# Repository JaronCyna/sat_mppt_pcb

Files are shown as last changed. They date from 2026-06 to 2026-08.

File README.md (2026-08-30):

# CubeSat 4-Channel Distributed MPPT & Electrical Power System (EPS)

A flight-ready 4-channel distributed Maximum Power Point Tracking (MPPT) battery charging and power distribution board designed in KiCad for CubeSat nanosatellite missions. Engineered for the Queen's Space Engineering Team (QSET) satellite branch.

---

## Key Features

* **4x Distributed Synchronous MPPT Buck Chargers (LTC4162)**:
  * 4 independent MPPT tracking channels (1 per CubeSat body face), eliminating partial shading and thermal mismatch losses across orbit.
  * Autonomous Constant-Current / Constant-Voltage (CC/CV) power-path management charging a 2S Li-ion battery bus (~8.4V nominal).
  * Phase-synchronized 1.5 MHz switching frequency via MCU clock distribution buffer to prevent harmonic beat frequencies and reduce EMI.
* **Microcontroller & Rad-Tolerant Storage Core**:
  * **STM32L496 ARM Cortex-M4**: Ultra-low-power MCU handling housekeeping telemetry, fault recovery, and bus communications.
  * **4 MB Radiation-Hardened MRAM**: Immune to Single-Event Upsets (SEU) and Total Ionizing Dose (TID), preserving black-box flight telemetry across power resets.
  * **4-Pin High-Vibration Crystal Oscillator**: Superior mechanical stability against rocket launch vibrational loads compared to traditional 2-pin crystals.
  * **Deterministic Hardware Watchdog (TPS3823A)**: Hardware supervisor with active-low reset and Schottky diode isolation protecting against SEU lockups in LEO.
* **Satellite Bus Communications & Auxiliary Power Path**:
  * **Dual Redundant CAN Bus Transceivers**: Conforms to European CubeSat standard bus communication architecture.
  * **I2C Bus Multiplexer (TI TCA9548A)**: 8-channel I2C switch addressing 4 identical LTC4162 chargers at fixed I2C addresses.
  * **Dual Synchronous Buck Converter (LTC3633)**: Monolithic dual synchronous buck generating regulated +3.3V and +5.0V system rails (<15 mV ripple).
  * **Autonomous Power-Path & Cold-Start (LTC4412)**: Ideal diode controller providing seamless fallback between battery and direct solar harvest for dead-battery bootstrapping.
* **Power Telemetry & Comprehensive eFuse Protection**:
  * **INA3221 Triple-Channel Current/Voltage Monitor**: Digital I2C telemetry reporting bus voltages, currents, and power consumption.
  * **TPS25947 Precision eFuses**: Dedicated protection on output rails with programmable current limits (1.33 A clamp on +3.3V), slew rate inrush control (5 V/ms), transient blanking (0.44 ms), hardware UVLO/OVLO windowing (3.02 V – 3.63 V), and remote MCU/OBC shutdown.
* **Form Factor & Mechanical Integrity**:
  * Standard PC/104 CubeSat stackable form factor.
  * Dedicated battery interface with 4-wire Kelvin sensing and NTC thermistor inputs.
  * 6-Layer stackup with solid ground reference planes, top-side RF/switching hot loops, and vibration-resistant soft-termination MLCC capacitors.

---

## System Architecture & PCB Renders

### Full Board 3D Model
Full Board 3D Model

### Top & Bottom Layout Renders
| Top Layer (Switching & Hot Loops) | Bottom Layer (Routing & Ground Shield) |
| :---: | :---: |
| Top Board | Bottom Board |

### Top-Level Hierarchical Schematic
Top-Level Schematic

---

## Technical Specifications

| Parameter | Specification / Value | Engineering Notes |
| :--- | :--- | :--- |
| **Solar Input Channels** | 4 independent MPPT channels | 1 channel per satellite face (up to ~18V $V_{\text{oc}}$ per string) |
| **Battery Bus Configuration** | 2S Li-ion (6.0V – 8.4V) | Direct autonomous CC/CV charging |
| **MPPT Switching Frequency** | 1.5 MHz (Synchronized) | Phase-locked via MCU PWM buffer to eliminate beat frequencies |
| **+3.3V Regulated Bus** | 3.3V @ 3A max (<15 mV ripple) | Generated by LTC3633 monolithic buck; eFuse clamped at 1.33A |
| **+5.0V Regulated Bus** | 5.0V @ 3A max (<15 mV ripple) | Generated by LTC3633 monolithic buck |
| **Telemetry Storage** | 4 MB SPI MRAM | Immune to SEU and TID radiation effects in LEO |
| **Bus Interfaces** | Dual CAN Bus + I2C | Redundant CubeSat standard bus communication |
| **PCB Stackup** | 6-Layer FR4 (1.6mm) | Top: Switching, L2: GND, L3: Mix, L4: Mix, L5: GND, L6: Digital |
| **Mechanical Standard** | PC/104 CubeSat Standard | Custom battery interface with Kelvin sense + NTC |

---

## Power Telemetry & eFuse Configuration

Each regulated rail is protected by a TI TPS25947 eFuse and monitored by a TI INA3221 current/voltage telemetry IC:

* **Current Limit Threshold ($I_{\text{LIM}}$)**:
  $$I_{\text{LIM}} = \frac{13.33}{R_{\text{ILIM}}\ [\text{k}\Omega]} = \frac{13.33}{10\text{ k}\Omega} = 1.33\text{ A}$$
* **Output Slew Rate & Inrush Control ($\frac{dV}{dt}$)**:
  $$\frac{dV}{dt} = \frac{500}{C_{dV/dt}\ [\text{pF}]} = \frac{500}{100\text{ pF}} = 5\text{ V/ms}$$
* **Overcurrent Fault Blanking Timer ($t_{\text{ITIMER}}$)**:
  $$t_{\text{ITIMER}} = C_{\text{ITIMER}}\ [\text{nF}] \times 0.2 = 2.2\text{ nF} \times 0.2 = 0.44\text{ ms}$$
* **Voltage Window (UVLO / OVLO)**:
  $$\text{Operational Window: } 3.02\text{ V} \le V_{\text{IN}} \le 3.63\text{ V}$$

---

## Hierarchical Schematic Structure

The hardware schematic is split into modular hierarchical sheets:

| Schematic Sheet | Description | Primary Components |
| :--- | :--- | :--- |
| `EPS_mppt_board.kicad_sch` | Root top-level hierarchical sheet | Interconnects and top-level bus routing |
| `MPPT_IC.kicad_sch` | Quad MPPT top-level sheet | 4x instances of `MPPT_indv.kicad_sch` |
| `MPPT_indv.kicad_sch` | Single-channel MPPT buck charger | LTC4162, power inductors, input/output caps |
| `3.3V.kicad_sch` | Dual synchronous buck converter | LTC3633 (generates +3.3V and +5.0V rails) |
| `MPPT_3.3V_logic.kicad_sch` | Power-path and bootstrapping | LTC4412 Ideal Diode Controller |
| `Sensing.kicad_sch` | Power telemetry and fault protection | INA3221 monitor, TPS25947 eFuses |
| `STM32L4.kicad_sch` | Microcontroller, MRAM, and clocking | STM32L496, 4MB MRAM, 4-pin OSC, 1:6 PWM buffer |
| `I2C.kicad_sch` | I2C bus multiplexer | TCA9548A 8-channel I2C switch |
| `External Watchdog IC.kicad_sch` | Deterministic hardware supervisor | TPS3823A watchdog IC + Schottky pull-up |
| `PC104.kicad_sch` | Satellite bus interface & connectors | PC/104 bus header, battery Kelvin sense, solar inputs |

---

## Repository Structure

```
Sat_MPPT_PCB/
├── .gitignore                      # Standard KiCad ignore rules
├── README.md                       # Board documentation and specifications
│
├── docs/                           # Documentation & exports
│   ├── bom/
│   │   └── EPS_mppt_board.csv      # Complete Bill of Materials
│   ├── pdf/
│   │   └── EPS_mppt_board.pdf      # Complete schematic PDF
│   └── svg/                        # Exported vector schematics per sheet
│       ├── EPS_mppt_board.svg
│       ├── EPS_mppt_board-3.3V Logic.svg
│       ├── EPS_mppt_board-MPPT IC.svg
│       └── ...
│
├── scripts/                        # Simulation & analysis tools
│   └── mppt_efficiency_sim.py      # 4-MPPT vs 1-MPPT orbital comparison simulation
│
├── archive/                        # Early design prototypes and iterations
│   └── prototypes/
│
├── 3D_Models/                      # 3D STEP/STP component models
│
├── sym-lib-table                   # KiCad Symbol Library Table
├── *.kicad_sym                     # Custom project symbol libraries
│
├── EPS_mppt_board.kicad_pro        # KiCad Project File
├── EPS_mppt_board.kicad_sch        # Root Schematic
├── EPS_mppt_board.kicad_pcb        # PCB Layout File
└── *.kicad_sch                     # Hierarchical Sub-schematics
```

---

## Simulation & Verification

* **Switching & Transient Simulations**:
  LTspice models verified buck converter stability, hot-loop parasitic response, and transient load step response (0.1A to 3.0A step with <15 mV voltage deviation).

* **SPICE**:
  All IC's with available SPICE models were simullated in PSPICE or LTSPICE.

---

## Project Background

* **Detailed Technical Writeup**: Read the full post on [Creating an MPPT System for Max Charge Efficiency on Satellite](https://jaroncyna.github.io/posts/MPPT-Satellite-Charger/)

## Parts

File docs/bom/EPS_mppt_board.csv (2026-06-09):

Reference | Qty | DNP | Exclude from BOM | Exclude from Board | Footprint | Datasheet | MANUFACTURER_PART_NUMBER | MANUFACTURER | Description
C1,C4,C5,C8,C11,C66,C67,C73,C74,C76 | 10 |  |  |  | Capacitor_SMD:C_0603_1608Metric | https://mm.digikey.com/Volume0/opasdata/d220001/medias/docus/2113/CL32B226KAJNFNE_Spec.pdf | 06035C104K4T2A | DigiKey | Unpolarized capacitor
C2,C58,C68,C69,C70 | 5 |  |  |  | Capacitor_SMD:C_0603_1608Metric | https://mm.digikey.com/Volume0/opasdata/d220001/medias/docus/2113/CL32B226KAJNFNE_Spec.pdf | CL10B105KQ8NNNC | DigiKey | Unpolarized capacitor
C3,C6,C7,C88,C89 | 5 |  |  |  | zLibrary:CAP_C2220C_2S_KEM-M |  | C2220C226MMR2L7289 | DigiKey | Unpolarized capacitor
C9,C77,C79,C81 | 4 |  |  |  | Capacitor_SMD:C_0603_1608Metric |  | GCM1885C1H222FA16D | DigiKey | Unpolarized capacitor
C10,C78,C80,C82 | 4 |  |  |  | Capacitor_SMD:C_0603_1608Metric |  | 885342206001 | DigiKey | Unpolarized capacitor
C12 | 1 |  |  |  | Capacitor_SMD:C_0603_1608Metric |  | C0603W102KDRACAUTO | DigiKey | Unpolarized capacitor
C13,C52,C53,C54,C55,C56,C57,C59,C62,C64,C65 | 11 |  |  |  | Capacitor_SMD:C_0603_1608Metric | kicad-embed://KEM_C1013_X7R_FT-CAP_SMD.pdf | C0603X104K5RACTU | DigiKey | Unpolarized capacitor,kicad-embed://KEM_C1013_X7R_FT-CAP_SMD.pdf
C14,C23,C32,C41 | 4 |  |  |  | Capacitor_SMD:C_0603_1608Metric | kicad-embed://CL10B105KQ8NNNC_Spec.pdf | CL10B105KQ8NNNC | DigiKey | Unpolarized capacitor
C15,C24,C33,C42 | 4 |  |  |  | Capacitor_SMD:C_0603_1608Metric |  | CL10B475KQ8NQNC | DigiKey | Unpolarized capacitor
C16,C22,C25,C31,C34,C40,C43,C49,C63 | 9 |  |  |  | zLibrary:CAP_C1210C_X7R_2S_FW_KEM-M |  | C1210C106M5R2C7186 | DigiKey | Unpolarized capacitor
C17,C18,C26,C27,C35,C36,C44,C45,C83,C84,C85,C87 | 12 |  |  |  | Capacitor_SMD:C_0603_1608Metric | ~ | 06035C104K4T2A | DigiKey | Unpolarized capacitor
C19,C28,C37,C46 | 4 |  |  |  | Capacitor_SMD:C_0603_1608Metric | ~ | CGA3E2X7R1H223K080AA | DigiKey | Unpolarized capacitor
C20,C29,C38,C47 | 4 |  |  |  | Capacitor_Tantalum_SMD:CP_EIA-7361-38_AVX-V | kicad-embed://t52.pdf | T52M9107M035C0055 | DigiKey | Unpolarized capacitor
C21,C30,C39,C48 | 4 |  |  |  | zLibrary:CAP_C2220C_2S_KEM-M |  | C2220C226MMR2L7289 | DigiKey | https://mm.digikey.com/Volume0/opasdata/d220001/medias/docus/2113/CL32B226KAJNFNE_Spec.pdf
C50 | 1 |  |  |  | Capacitor_Tantalum_SMD:CP_EIA-7361-38_AVX-V | kicad-embed://t52.pdf | T52M9107M035C0055 | DigiKey | Polarized capacitor, US symbol
C51 | 1 |  |  |  | Capacitor_SMD:C_0603_1608Metric |  | CL10B475KQ8NQNC | DigiKey | Unpolarized capacitor
C60,C61 | 2 |  |  |  | Capacitor_SMD:C_0603_1608Metric |  | 06035C100K4T4A | DigiKey | Unpolarized capacitor
C71,C72,C75 | 3 |  |  |  | zLibrary:CAP_C1210C_X7R_2S_FW_KEM-M |  | C1210C106M5R2C7186 | DigiKey | Unpolarized capacitor
C86 | 1 |  |  |  | Capacitor_SMD:C_0603_1608Metric |  | GRM188Z71E225KE43D | DigiKey | Unpolarized capacitor
D1 | 1 |  |  | Excluded from board | Diode_SMD:D_SOD-323F | ~ | RBE01VYM6AFHTR | Digikey | Schottky diode
D6 | 1 |  |  |  | LED_SMD:LED_0603_1608Metric |  | 150060RS55040 | DigiKey | Light emitting diode
D7 | 1 |  |  |  | LED_SMD:LED_0603_1608Metric |  | 150060VS55040 | DigiKey | Light emitting diode
D8 | 1 |  |  |  | LED_SMD:LED_0603_1608Metric |  | 150060BS55040 | DigiKey | Light emitting diode
D9,D10,D11,D12 | 4 |  |  |  | Diode_SMD:D_SMA |  |  | DigiKey | 400W unidirectional Transient Voltage Suppressor, 22.0Vr, SMA(DO-214AC)
FB1 | 1 |  |  |  | Inductor_SMD:L_0603_1608Metric |  | BLM18AG601SN1D | DigiKey | Ferrite bead
J1 | 1 |  |  |  | Connector_JST:JST_EH_B4B-EH-A_1x04_P2.50mm_Vertical | ~ |  | DigiKey | Generic connector, single row, 01x04, script generated
J2 | 1 |  |  |  | zLibrary:SAMTEC_ESQT-126-X-X-Q-X |  |  | Samtec
JP1,JP3 | 2 |  | Excluded from BOM |  | Jumper:SolderJumper-2_P1.3mm_Open_TrianglePad1.0x1.5mm |  |  |  | Solder Jumper, 2-pole, open
JP2 | 1 |  | Excluded from BOM |  | Jumper:SolderJumper-2_P1.3mm_Open_TrianglePad1.0x1.5mm |  |  |  | Solder Jumper, 3-pole, open
L1 | 1 |  |  |  | zLibrary:IND_BOURNS_SRR6038 |  | SRR6038-100Y | DigiKey | Inductor
L2,L3,L4,L5 | 4 |  |  |  | zLibrary:IND_SRP7028A-4R7M_BRN-M |  | SRP7028A-4R7M | DigiKey | Inductor
L6 | 1 |  |  |  | zLibrary:IND_SRP4020_BRN-M |  | SRP4020TA-1R5M | DigiKey | Inductor
L7 | 1 |  |  |  | zLibrary:IND_PA4332_PUL-M |  | PA4332.102NLT | DigiKey | Inductor
Q4,Q5,Q6,Q7,Q8,Q9,Q10,Q11,Q12,Q13,Q14 | 11 |  |  |  | Package_TO_SOT_SMD:LFPAK56 |  | PSMN4R0-40YS,115 |  | N-MOSFET transistor, drain/source/gate
Q15,Q16,Q17 | 3 |  |  |  | Package_SO:PowerPAK_SO-8_Single |  |  |  | -60A Id, -20V Vds, 1.9 mOhm Ron, PowerPAK-8
R1,R2,R5,R71,R72,R73,R82,R84,R85 | 9 |  |  |  | Resistor_SMD:R_0603_1608Metric | ~ | AT0603FRE07100KL | Digikey | Resistor
R3,R7 | 2 |  |  |  | Resistor_SMD:R_0603_1608Metric | ~ | RN73R1JTTD4703F50 | Digikey | Resistor
R4 | 1 |  |  |  | Resistor_SMD:R_0603_1608Metric | ~ | RN73R1JTTD3483F25 | Digikey | Resistor
R6,R81 | 2 |  |  |  | Resistor_SMD:R_0603_1608Metric | ~ | RN73R1JTTD4991F100 | Digikey | Resistor
R8 | 1 |  |  |  | Resistor_SMD:R_0603_1608Metric | ~ | RN73R1JTTD6653F25 | Digikey | Resistor
R9 | 1 |  |  |  | Resistor_SMD:R_0603_1608Metric | ~ | RN73R1JTTD1653F25 | Digikey | Resistor
R10 | 1 |  |  |  | Resistor_SMD:R_0603_1608Metric | ~ | RN73R1JTTD4993F25 | Digikey | Resistor
R11,R15,R17,R22,R24,R29,R31,R36,R38,R40,R42,R47,R48,R59,R60,R61,R62,R63,R80,R83,R86,R87,R88,R89,R90,R93,R95 | 27 |  |  |  | Resistor_SMD:R_0805_2012Metric | ~ | TNPW080510K0FEEA | Digikey | Resistor
R12,R19,R26,R33 | 4 |  |  |  | Resistor_SMD:R_0805_2012Metric | ~ | MFCR0805F2R70QHR | Digikey | Resistor
R13,R14,R20,R21,R27,R28,R34,R35 | 8 |  |  |  | Resistor_SMD:R_0603_1608Metric | ~ | MCT0603MC4701FP500 | Digikey | Resistor
R16,R23,R30,R37 | 4 |  |  |  | Resistor_SMD:R_0815_2038Metric | ~ | RL3720WT-R025-G | Digikey | Resistor
R18,R25,R32,R39 | 4 |  |  |  | Resistor_SMD:R_0603_1608Metric | ~ | RQ73C1J63K4BTD | Digikey | Resistor
R41 | 1 |  |  |  | Resistor_SMD:R_0603_1608Metric | ~ | MCT0603MZ0000ZP500 | Digikey | Resistor
R43,R44,R45 | 3 |  |  |  | Resistor_SMD:R_0603_1608Metric | ~ | RG1608P-331-B-T5 | Digikey | Resistor
R46 | 1 |  |  |  | Resistor_SMD:R_0603_1608Metric | ~ | MCT0603MC1200FP500 | DigiKey | Resistor
R49,R50,R51,R52,R53,R54,R55,R56 | 8 |  |  |  | Resistor_SMD:R_0603_1608Metric | ~ | AT0603FRE072K2L | Digikey | Resistor
R57,R64,R65,R67,R68,R70 | 6 |  |  |  | Resistor_SMD:R_0805_2012Metric | ~ | TNPW080510R0BEEA | Digikey | Resistor
R58,R66,R69 | 3 |  |  |  | Resistor_SMD:R_0815_2038Metric | ~ | RL3720WT-R004-F | Digikey | Resistor
R74,R76 | 2 |  |  |  | Resistor_SMD:R_0603_1608Metric | ~ |  |  | Resistor
R75 | 1 |  |  |  | Resistor_SMD:R_0603_1608Metric | ~ |  |  | Resistor
R77,R79 | 2 |  |  |  | Resistor_SMD:R_0603_1608Metric | ~ |  |  | Resistor
R78 | 1 |  |  |  | Resistor_SMD:R_0603_1608Metric | ~ |  |  | Resistor
R91 | 1 |  |  |  | Resistor_SMD:R_0603_1608Metric | ~ |  |  | Resistor
R92 | 1 |  |  |  | Resistor_SMD:R_0603_1608Metric | ~ |  |  | Resistor
R94 | 1 |  |  |  | Resistor_SMD:R_0603_1608Metric | ~ |  |  | Resistor
U1,U4 | 2 |  |  |  | Package_TO_SOT_SMD:TSOT-23-6 | https://www.analog.com/media/en/technical-documentation/data-sheets/4412fb.pdf |  |  | Low Loss PowerPath Controller, TSOT-23-6
U2,U16,U17,U18 | 4 |  |  |  | zLibrary:RPW0010A-MFG | https://www.ti.com/lit/gpn/tps25947
U3 | 1 |  |  |  | zLibrary:DQC0010A | https://www.ti.com/lit/gpn/tps62175
U5 | 1 |  |  |  | IC's_Sat:DFN-8_DD_LIT | https://www.analog.com/media/en/technical-documentation/data-sheets/2965fc.pdf
U6 | 1 |  |  |  | Package_TO_SOT_SMD:SOT-23-5_HandSoldering | https://www.ti.com/lit/gpn/tps3823
U7,U8,U9,U10 | 4 |  |  |  | Package_DFN_QFN:QFN-28-1EP_4x5mm_P0.5mm_EP2.65x3.65mm_ThermalVias |  |  | Analog Devices
U11 | 1 |  |  |  | Package_DFN_QFN:DFN-8-1EP_6x5mm_P1.27mm_EP4x4mm | https://www.everspin.com/file/217/download |  |  | 4Mb MRAM memory with SPI interface, DFN-8
U12 | 1 |  |  |  | Package_SO:SOIC-8_3.9x4.9mm_P1.27mm | http://www.ti.com/lit/ds/symlink/tcan337.pdf |  |  | High-Speed CAN Transceiver, 1Mbps, 3.3V supply, low power standby mode, shutdown mode, SOT-23-8/SOIC-8
U13 | 1 |  |  |  | Package_DFN_QFN:Texas_RGE0024C_VQFN-24-1EP_4x4mm_P0.5mm_EP2.1x2.1mm | http://www.ti.com/lit/ds/symlink/tca9548a.pdf |  |  | Low voltage 8-channel I2C switch with reset, VQFN-24
U15 | 1 |  |  |  | Package_DFN_QFN:Texas_RGV0016A_VQFN-16-1EP_4x4mm_P0.65mm_EP2.1x2.1mm | http://www.ti.com/lit/ds/symlink/ina3221.pdf |  |  | Triple-Channel High-Side Shunt and Bus Voltage Monitor with I2C and SMBUS Compatible Interface, QFN-16
U19 | 1 |  |  |  | Package_DFN_QFN:QFN-28-1EP_4x5mm_P0.5mm_EP2.65x3.65mm_ThermalVias |  | ltc3633aiufd#pbf
U20 | 1 |  |  |  | Package_QFP:LQFP-64_10x10mm_P0.5mm | https://www.st.com/resource/en/datasheet/stm32l476rg.pdf |  |  | STMicroelectronics Arm Cortex-M4 MCU, 1024KB flash, 128KB RAM, 80 MHz, 1.71-3.6V, 51 GPIO, LQFP64
Y1 | 1 |  |  |  | Crystal:Crystal_SMD_3225-4Pin_3.2x2.5mm | ~ |  |  | Four pin crystal, GND on pins 2 and 3

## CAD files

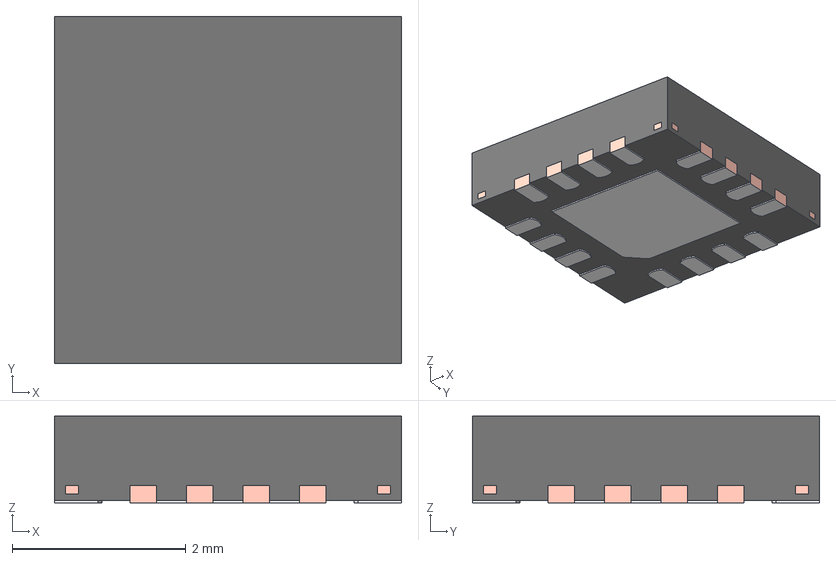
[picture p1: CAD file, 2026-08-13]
3D_Models/INA3221AIRGVT.stp
4.00 x 4.00 x 1.00 mm
FRAME
PIN1_AREA

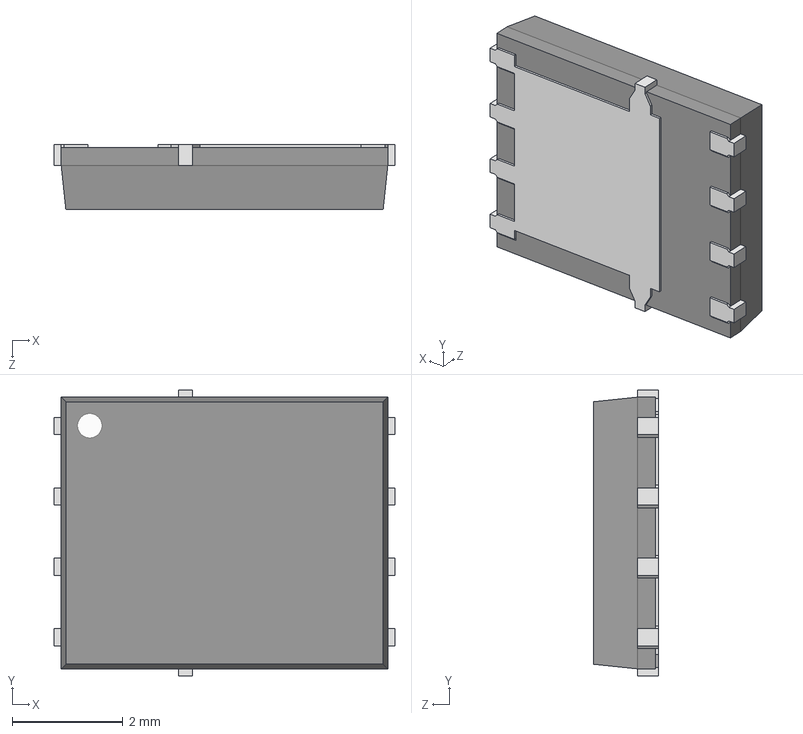
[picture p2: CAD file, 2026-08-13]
3D_Models/SIR5607DP-T1-RE3.stp
6.15 x 5.15 x 1.17 mm
Vishay SIR186DP-T1-RE3 1.STEP
Vishay SIR186DP-T1-RE3 2.STEP

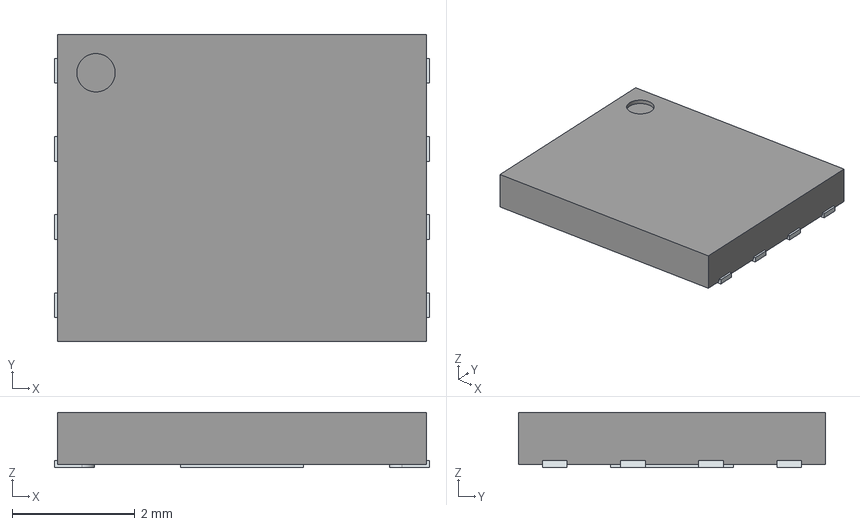
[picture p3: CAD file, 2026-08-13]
3D_Models/MR20H40CDF.stp
6.10 x 5.00 x 0.9 mm
ThermalPin
PinsArrayLR

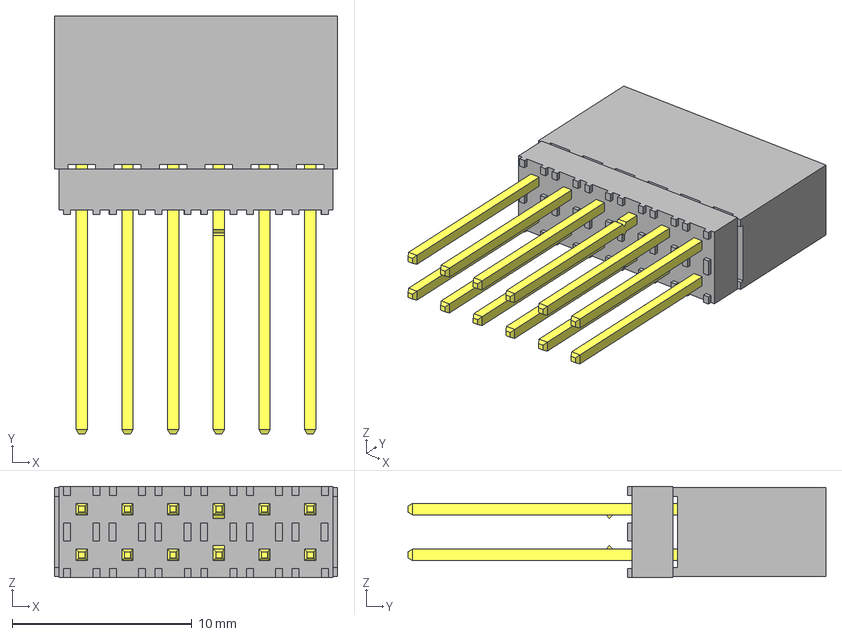
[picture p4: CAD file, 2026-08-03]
3D_Models/ESQ-106-39-G-D-LL.stp
15.7 x 23.2 x 5.08 mm
ESQ-106-39-G-D-LL_socket
ESQ-106-39-G-D-LL_pins
ESQ-106-39-G-D-LL2_pins
ESQ-106-39-G-D-LL_bpins

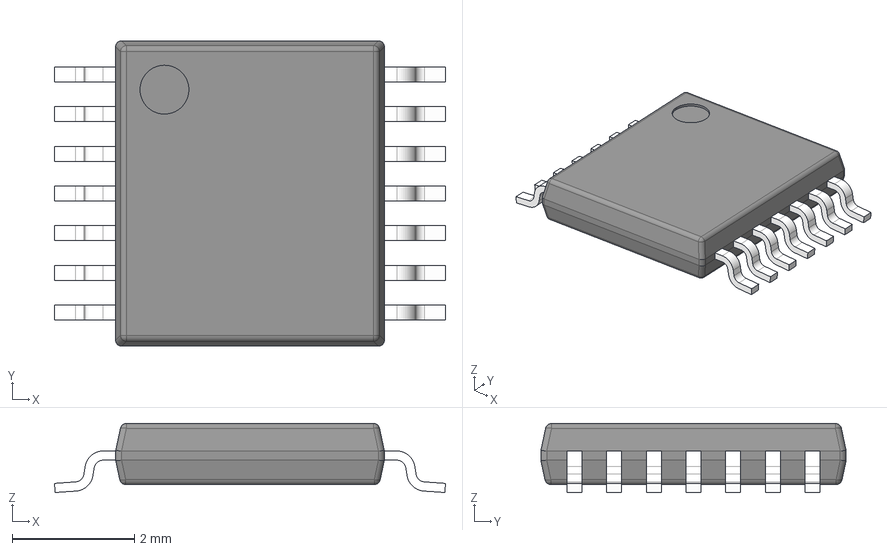
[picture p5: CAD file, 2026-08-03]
3D_Models/PW0014A.stp
6.40 x 5.00 x 1.13 mm
BODY-TSSOP
LEAD-TSSOP x 14
PIN1

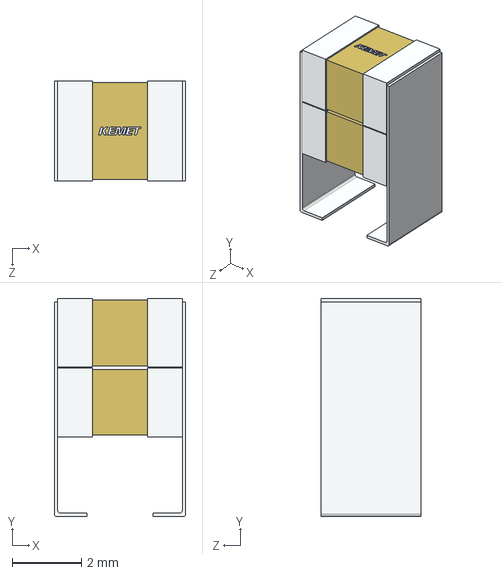
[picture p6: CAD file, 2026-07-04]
3D_Models/C1210C106M5R2C7186.step
3.80 x 6.30 x 2.90 mm

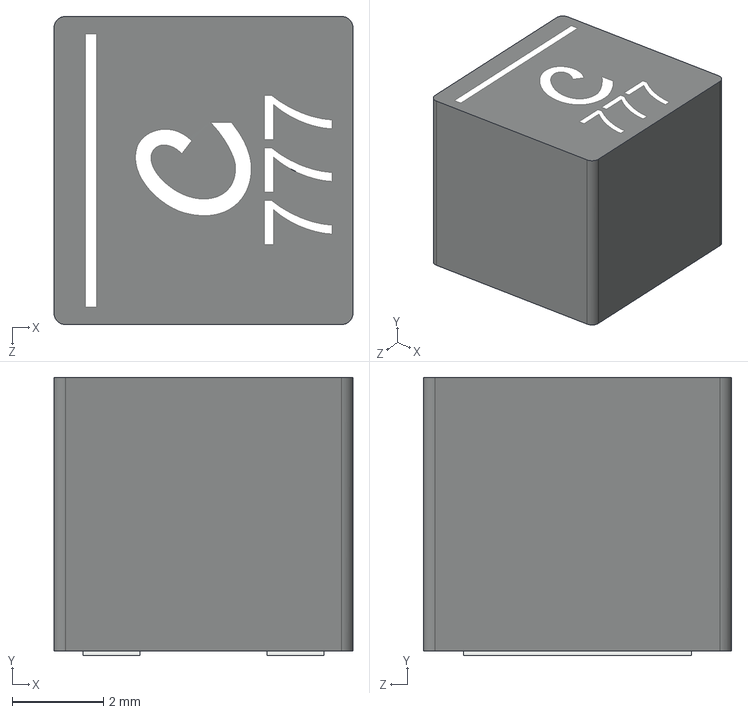
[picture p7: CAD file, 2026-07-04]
3D_Models/XAL6060-472MEC.stp
6.56 x 6.10 x 6.76 mm

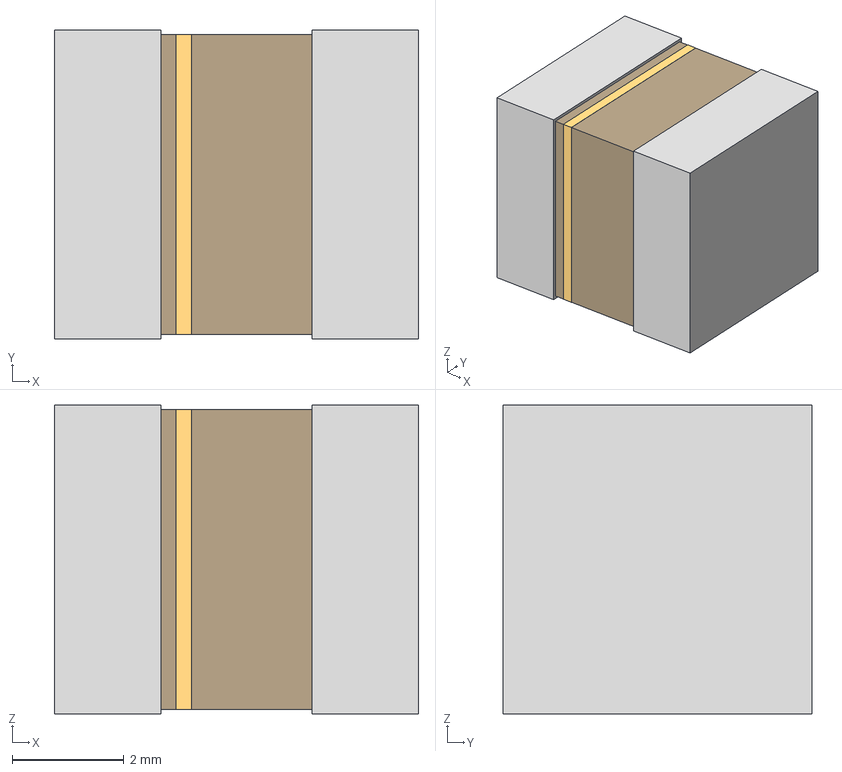
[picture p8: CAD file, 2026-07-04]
3D_Models/CAP_C2220C_2S_KEM.step
6.50 x 5.51 x 5.51 mm

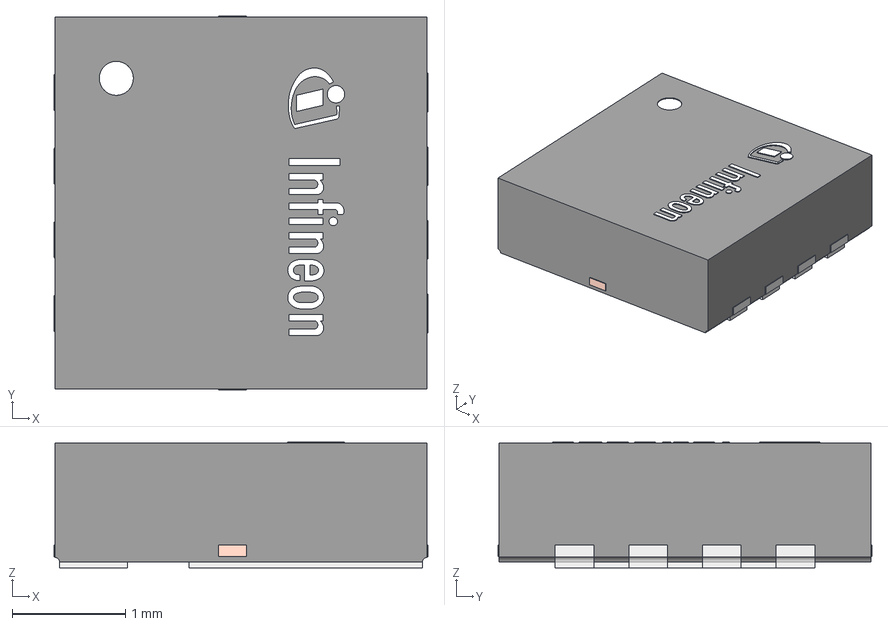
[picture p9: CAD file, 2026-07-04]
3D_Models/PG-TSDSON-8-44_Z8B00251735_V01_3D.stp
3.30 x 3.30 x 1.11 mm

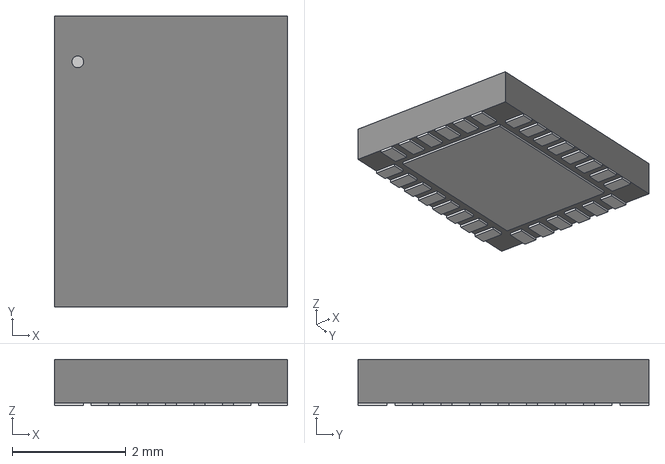
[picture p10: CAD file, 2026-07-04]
3D_Models/LTC4162.step
4.09 x 5.11 x 0.815 mm

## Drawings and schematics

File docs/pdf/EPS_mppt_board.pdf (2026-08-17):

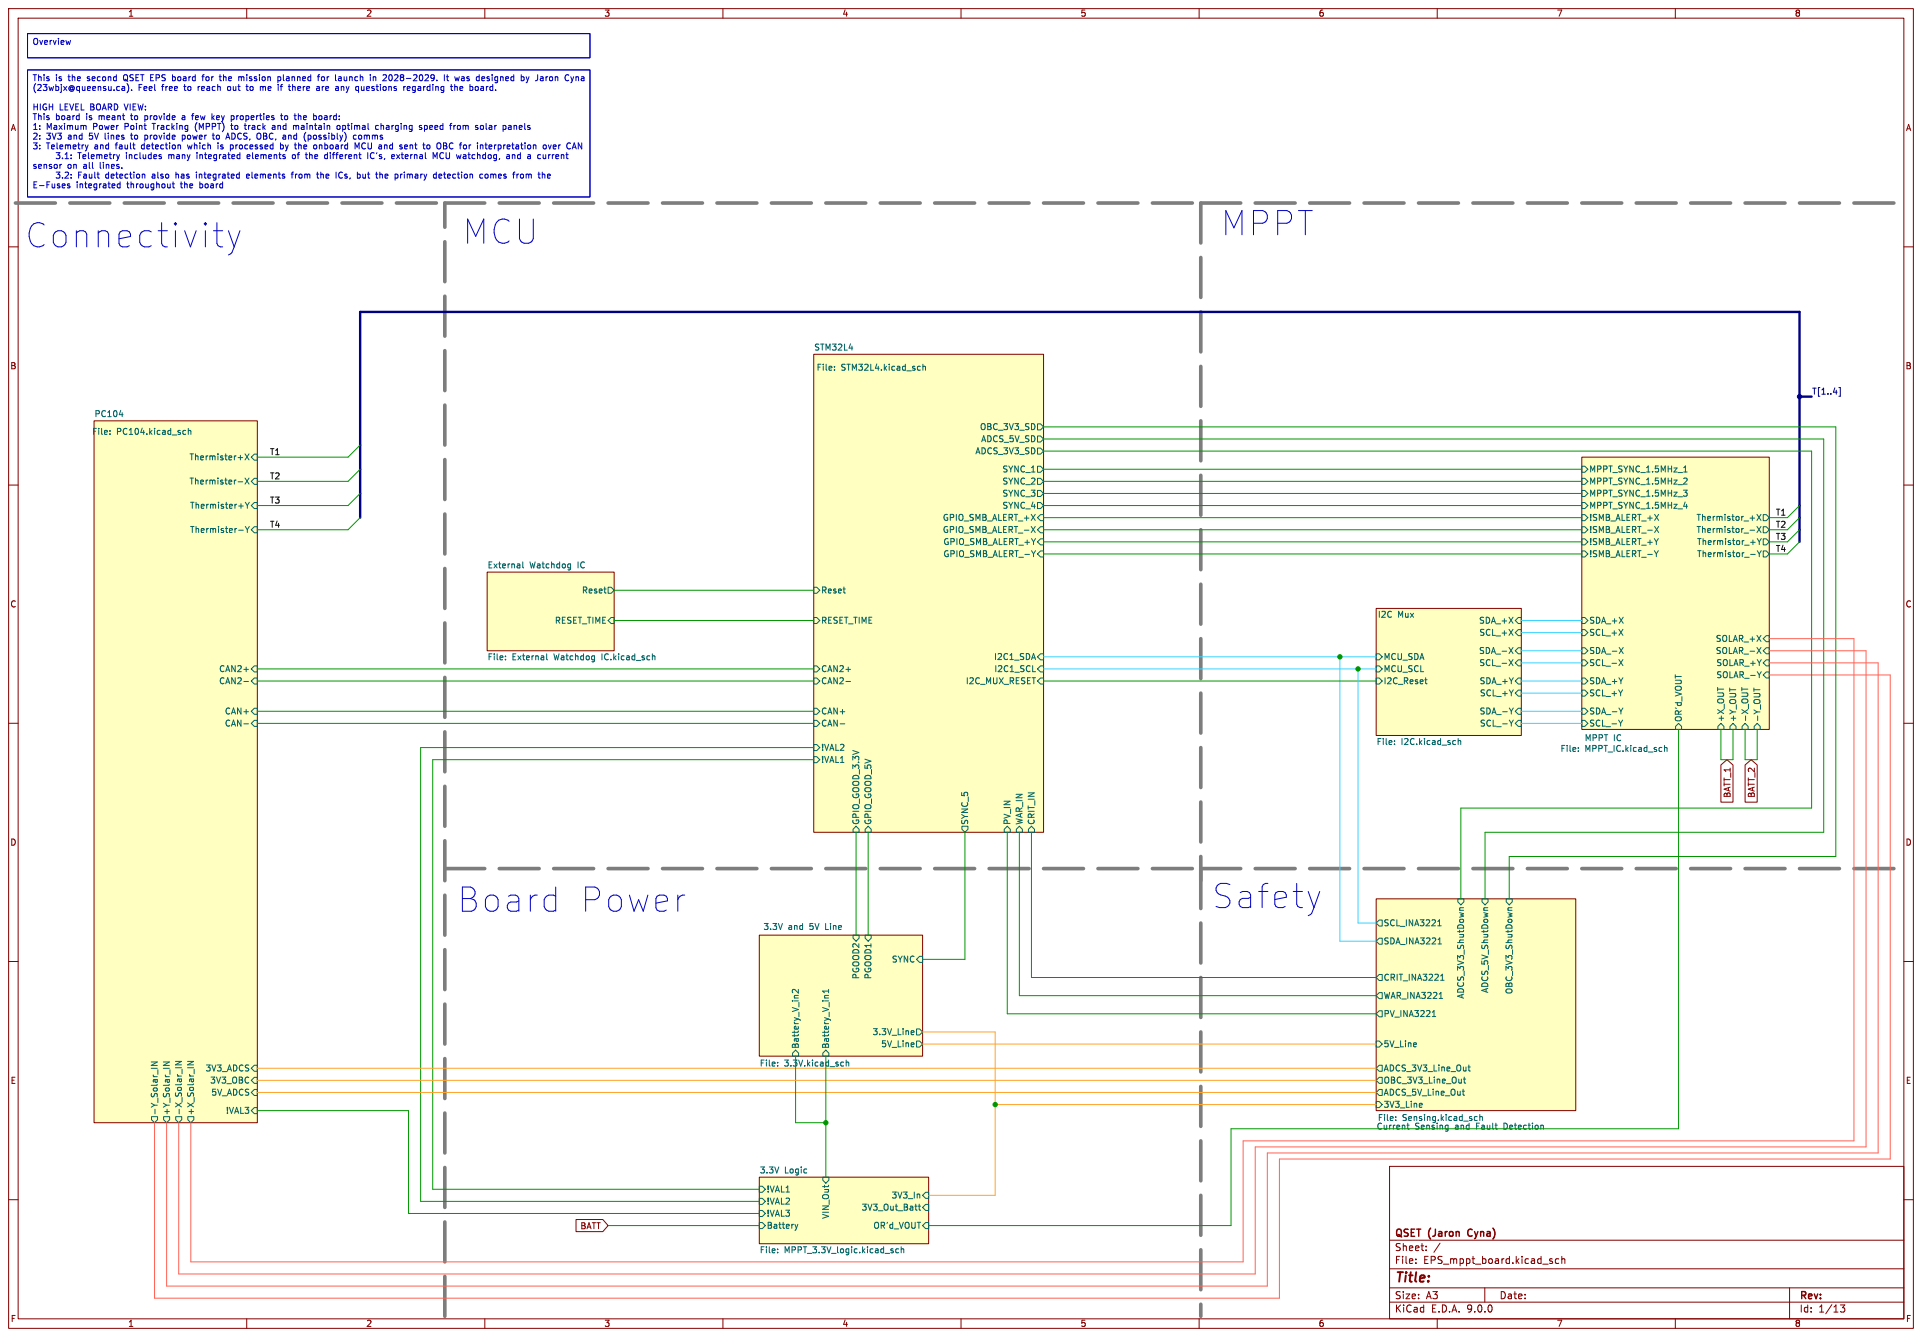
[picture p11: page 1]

File: MPPT_IC.kicad_sch RESET_TIME Reset External Watchdog IC

3V3_Line ADCS_3V3_Line_Out OBC_3V3_Line_Out ADCS_5V_Line_Out Current Sensing and Fault Detection File: Sensing.kicad_sch

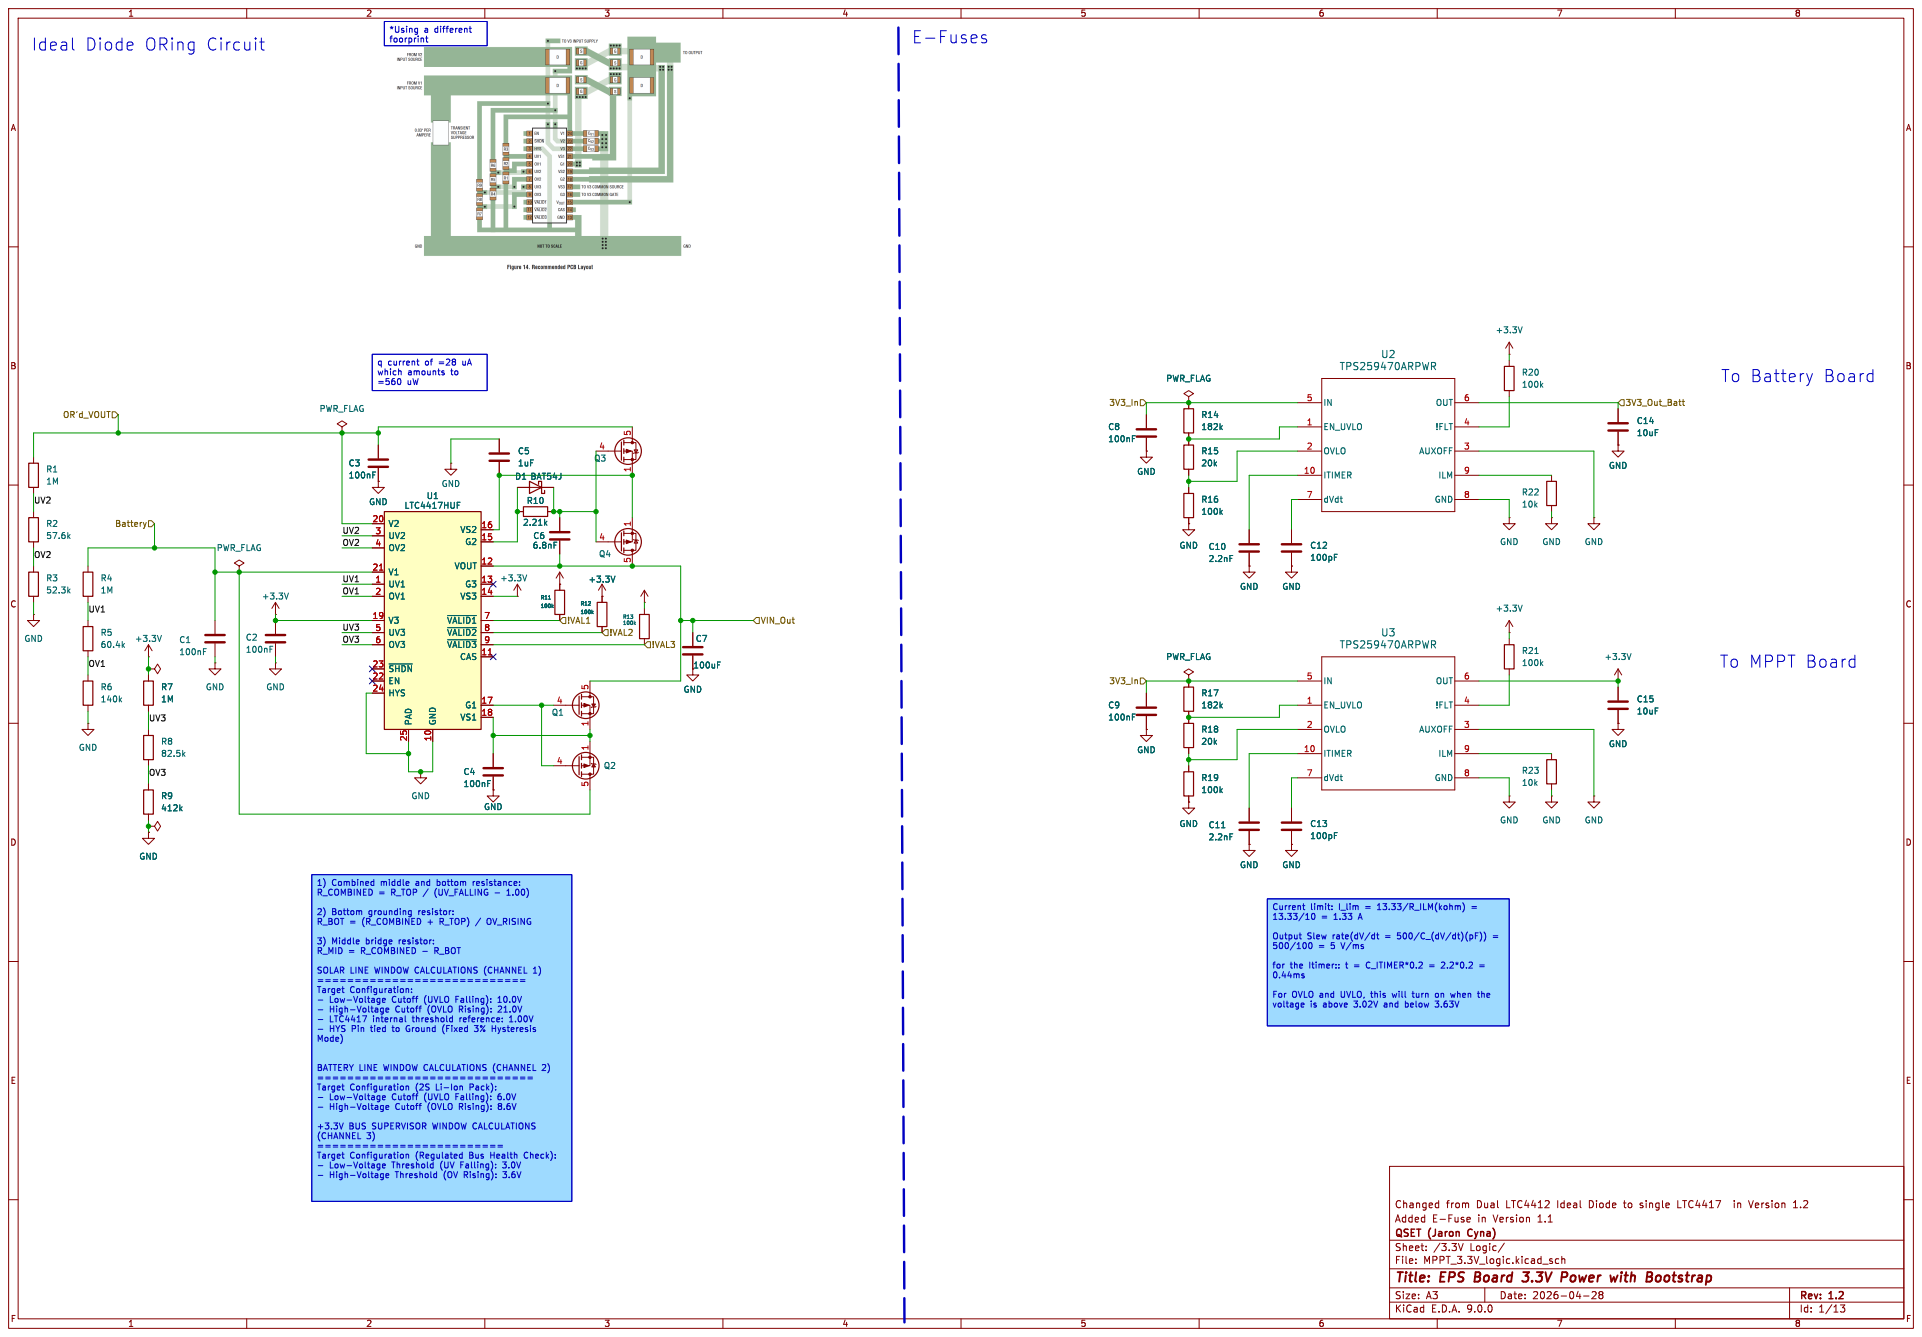
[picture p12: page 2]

foorprint q current of =28 uA which amounts to =560 uW

Ideal Diode ORing Circuit

1) Combined middle and bottom resistance: R_COMBINED = R_TOP / (UV_FALLING - 1.00)

0.44ms For OVLO and UVLO, this will turn on when the

voltage is above 3.02V and below 3.63V

- HYS Pin tied to Ground (Fixed 3% Hysteresis

+3.3V BUS SUPERVISOR WINDOW CALCULATIONS

Id: 1/13 Title: EPS Board 3.3V Power with Bootstrap

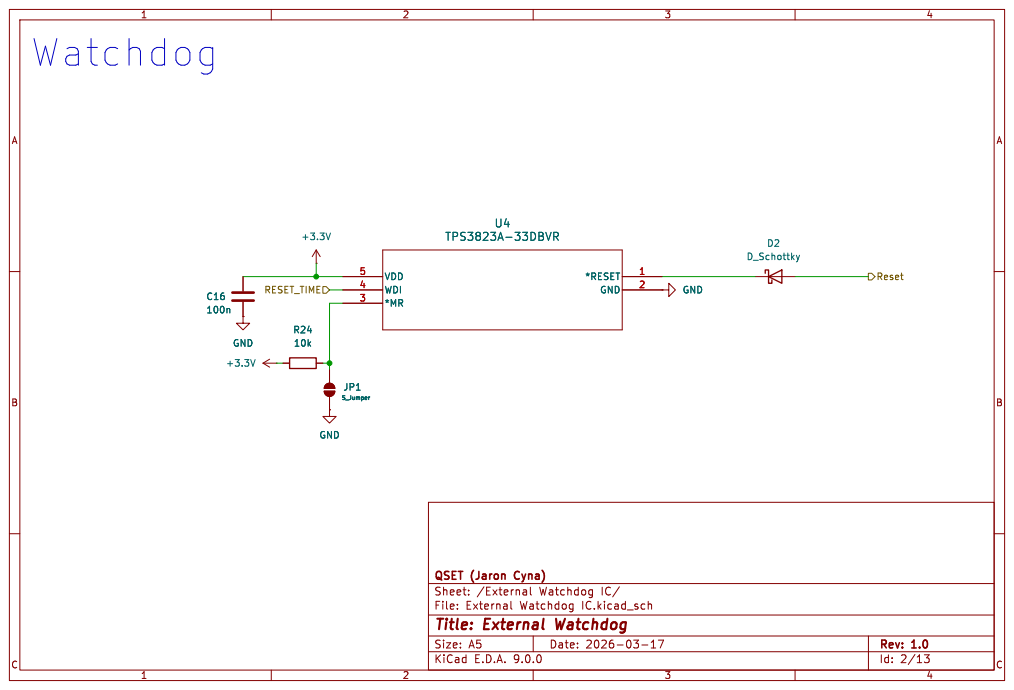
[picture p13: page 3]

Id: 2/13 Title: External Watchdog

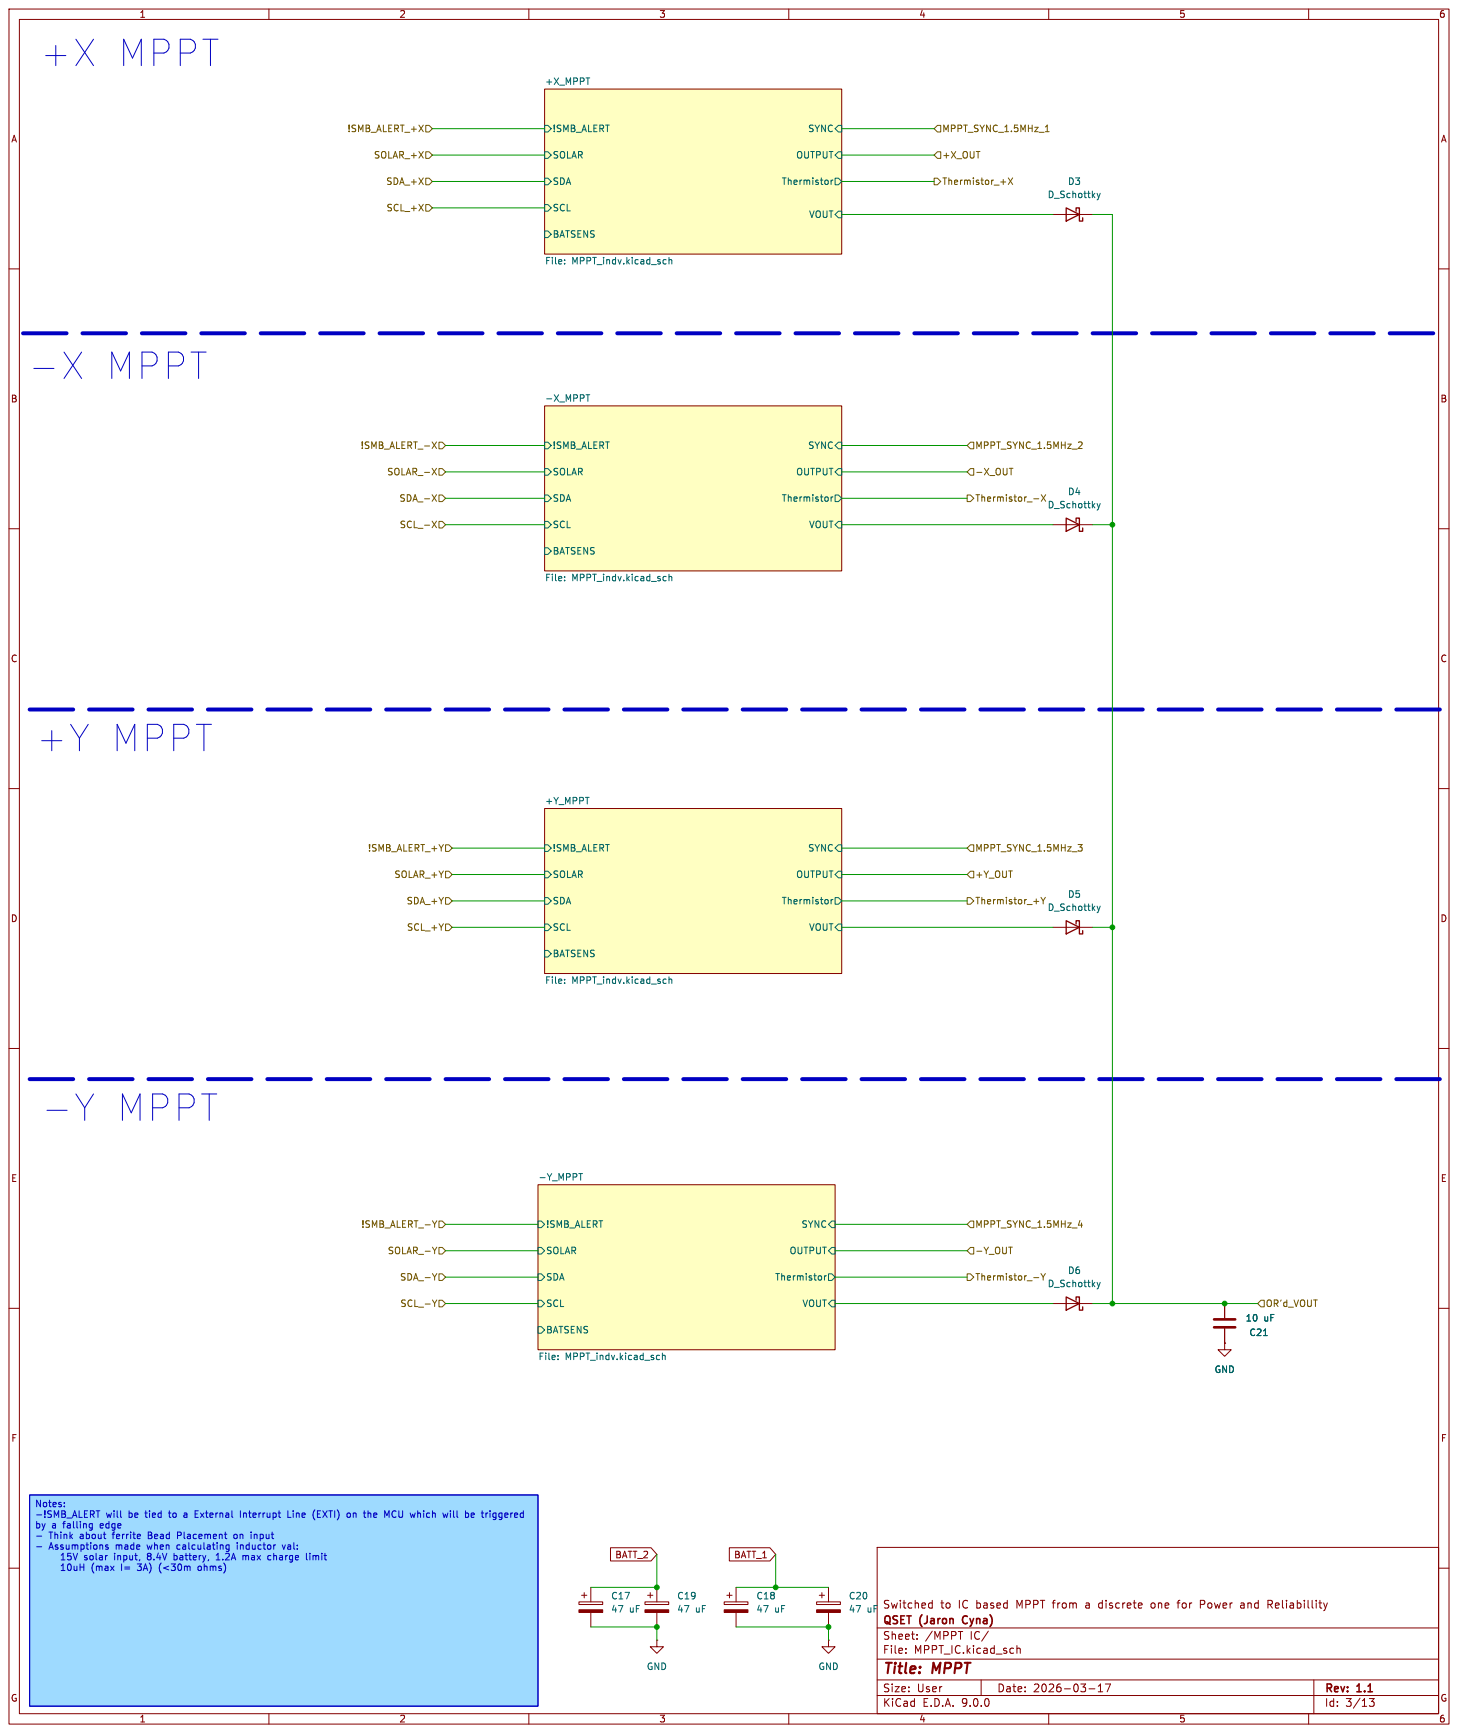
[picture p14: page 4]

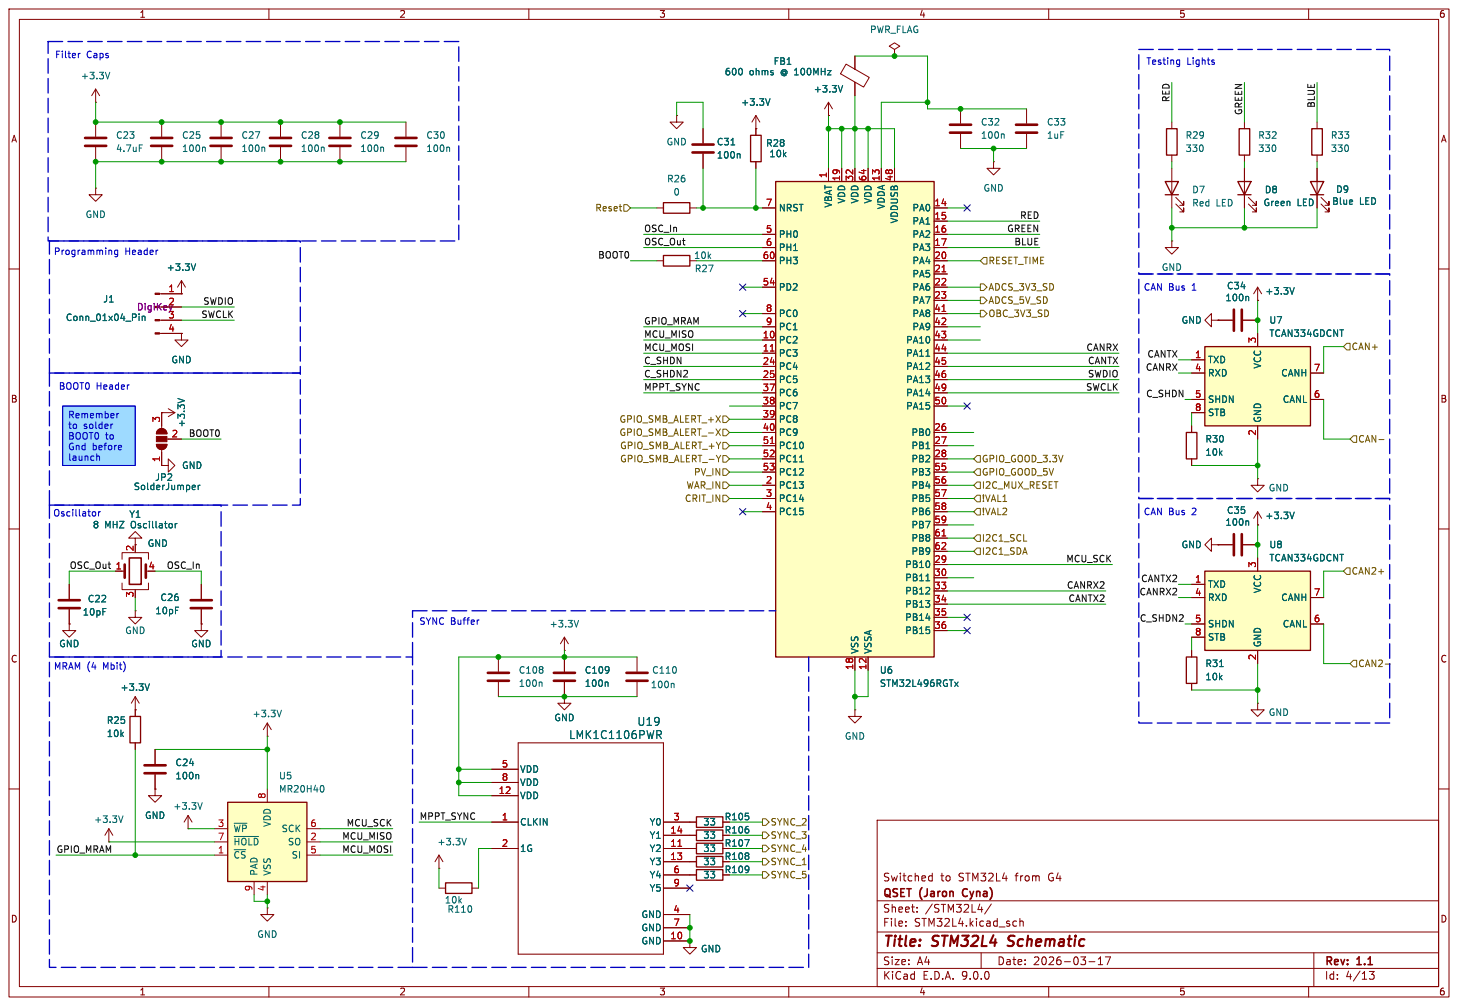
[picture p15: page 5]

1 VDD 19 VDD 32 VSS 18 VDD 64 VSSA 12 VDDA 13 VDDUSB 48 PA0 14 PA1 15 PA2 16 PA3 17 PA4 20 PA5 21 PA6 22 PA7 23 PA8 41 PA9 42 PA10 43 PA11 44 PA12 45 PA13 46 PA14 49 PA15 50 PB0 26 PB1 27 PB2 28 PB3 55 PB4 56 PB5 57 PB6 58 PB7 59 PB8 61 PB9 62 PB10 29 PB11 30 PB12 33 PB13 34 PB14 35 PB15 36 U6STM32L496RGTx R30

1 VDD 19 VDD 32 VSS 18 VDD 64 VSSA 12 VDDA 13 VDDUSB 48 PA0 14 PA1 15 PA2 16 PA3 17 PA4 20 PA5 21 PA6 22 PA7 23 PA8 41 PA9 42 PA10 43 PA11 44 PA12 45 PA13 46 PA14 49 PA15 50 PB0 26 PB1 27 PB2 28 PB3 55 PB4 56 PB5 57 PB6 58 PB7 59 PB8 61 PB9 62 PB10 29 PB11 30 PB12 33 PB13 34 PB14 35 PB15 36 D8 Green LED

C_SHDN2 BOOT0 Remember
to solder BOOT0 to Gnd before

4 SCK 6 SO 2 SI 5 U5 MR20H40 GND

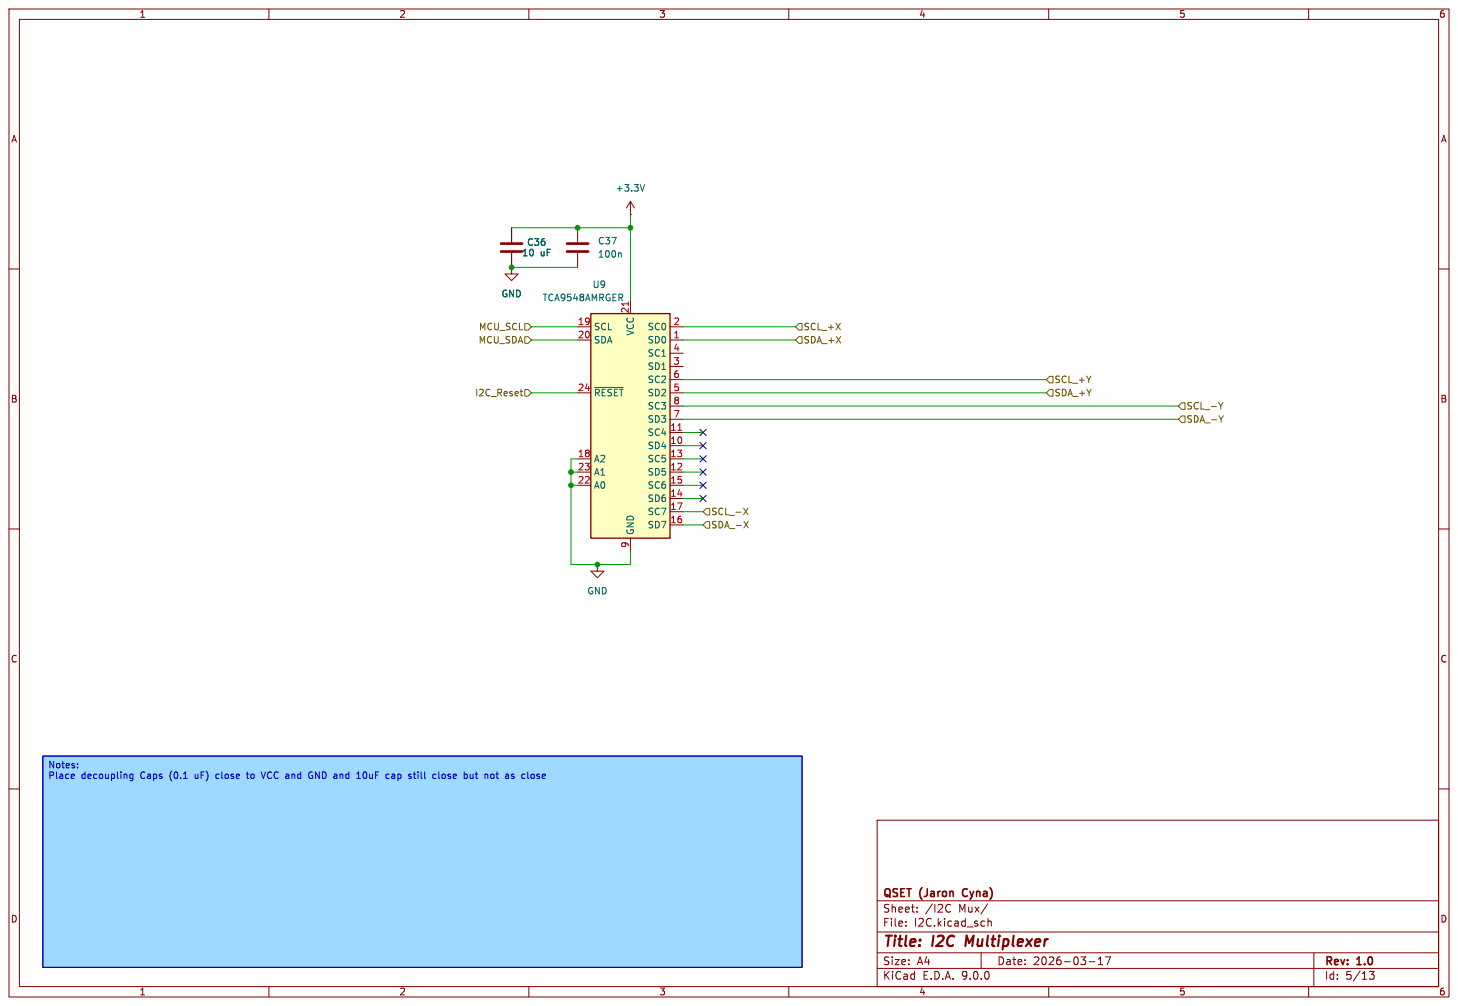
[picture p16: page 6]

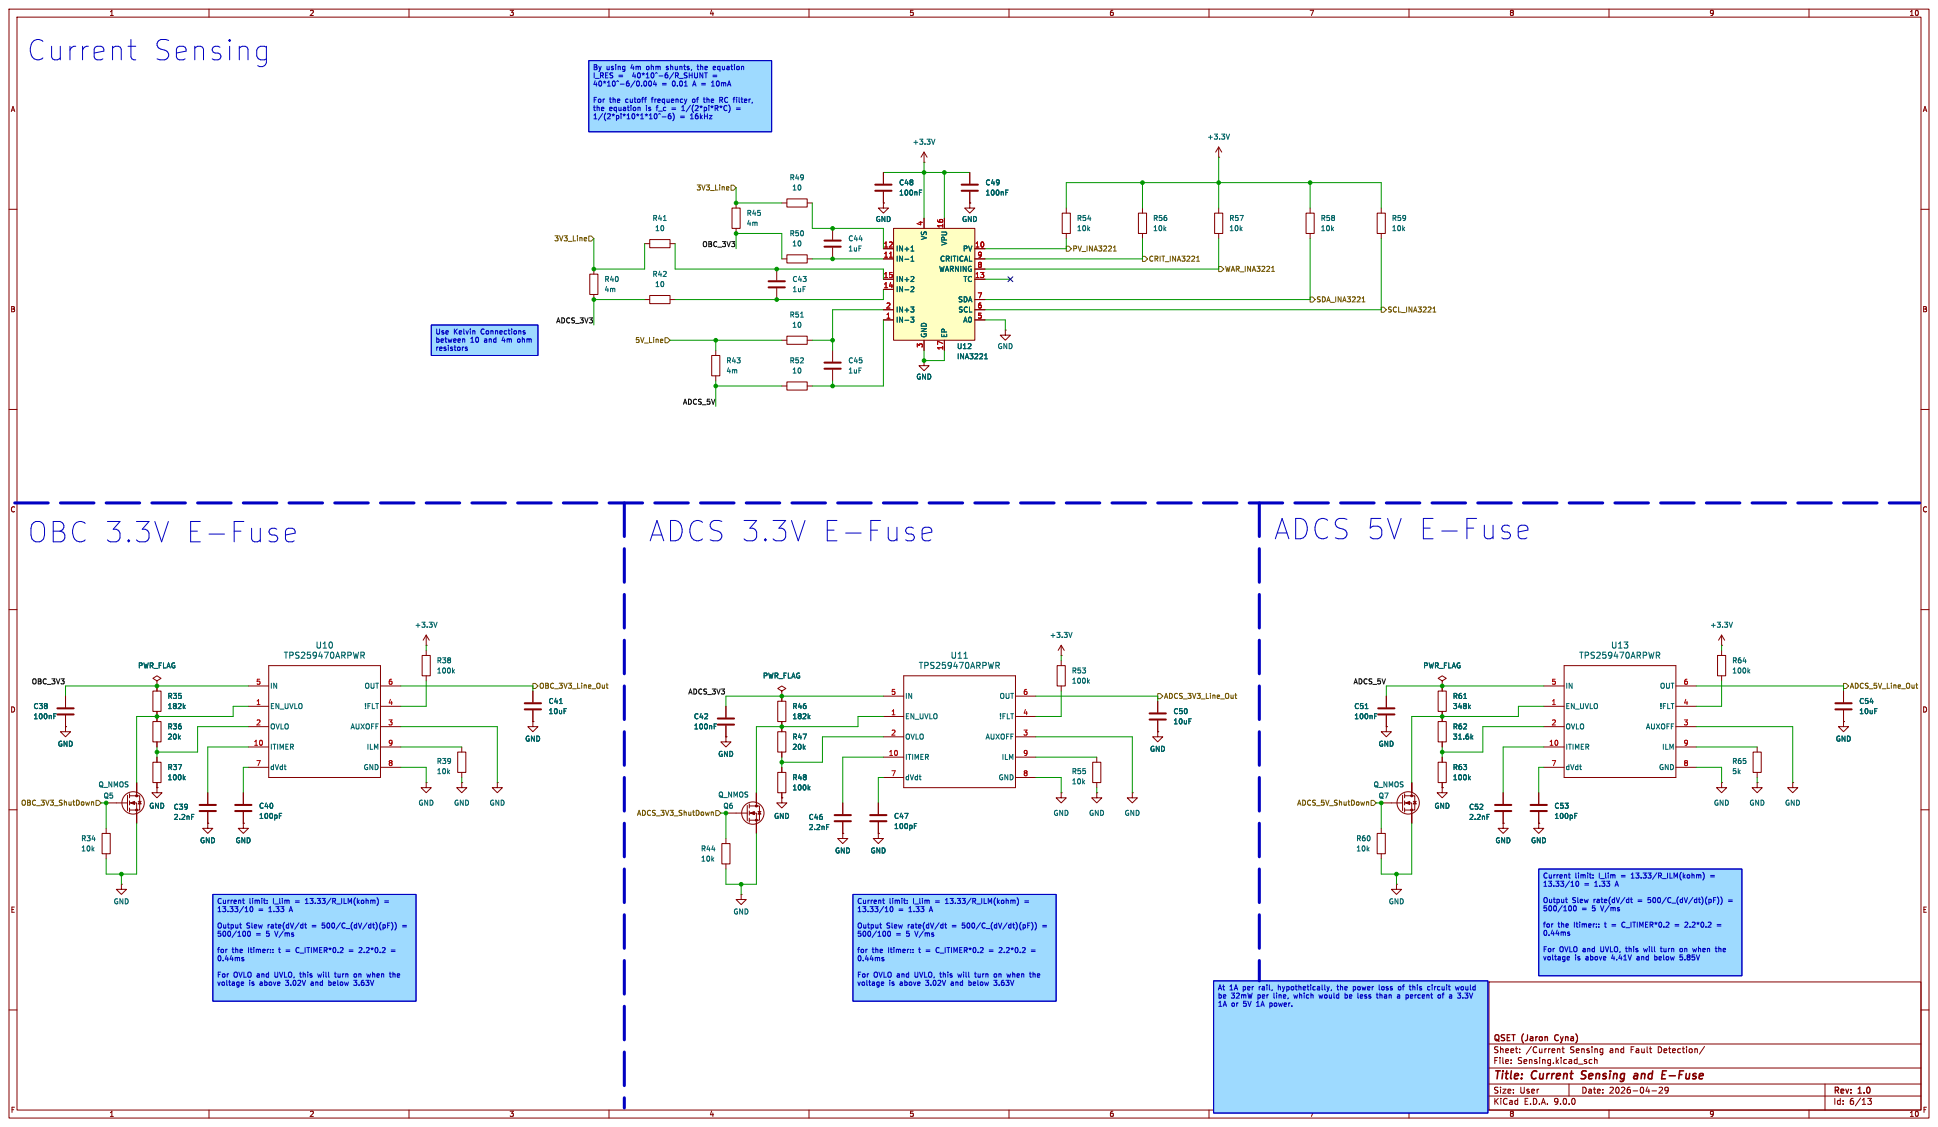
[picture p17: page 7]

By using 4m ohm shunts, the equation

3 VPU 16 EP 17 PV 10 CRITICAL 9 WARNING 8 TC 13 SDA 7 SCL 6 A0 5 GND

3 VPU 16 EP 17 PV 10 CRITICAL 9 WARNING 8 TC 13 SDA 7 SCL 6 A0 5 U12

Use Kelvin Connections between 10 and 4m ohm

0.44ms For OVLO and UVLO, this will turn on when the

voltage is above 4.41V and below 5.85V

voltage is above 3.02V and below 3.63V

be 32mW per line, which would be less than a percent of a 3.3V

Id: 6/13 Title: Current Sensing and E-Fuse

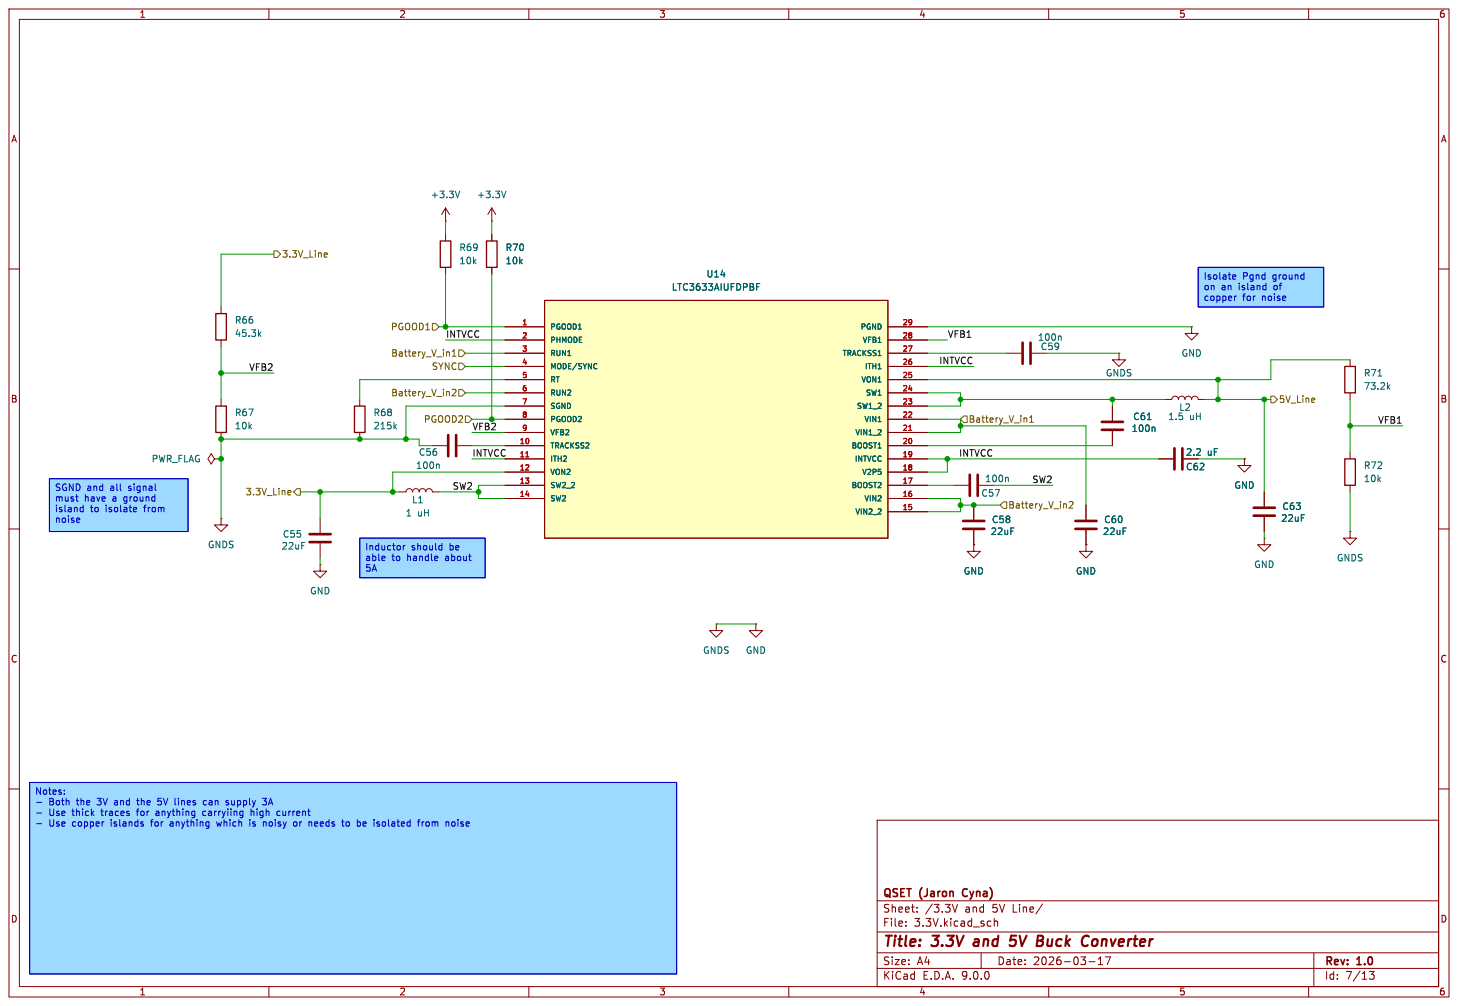
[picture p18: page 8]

Isolate Pgnd ground
on an island of copper for noise

island to isolate from
noise

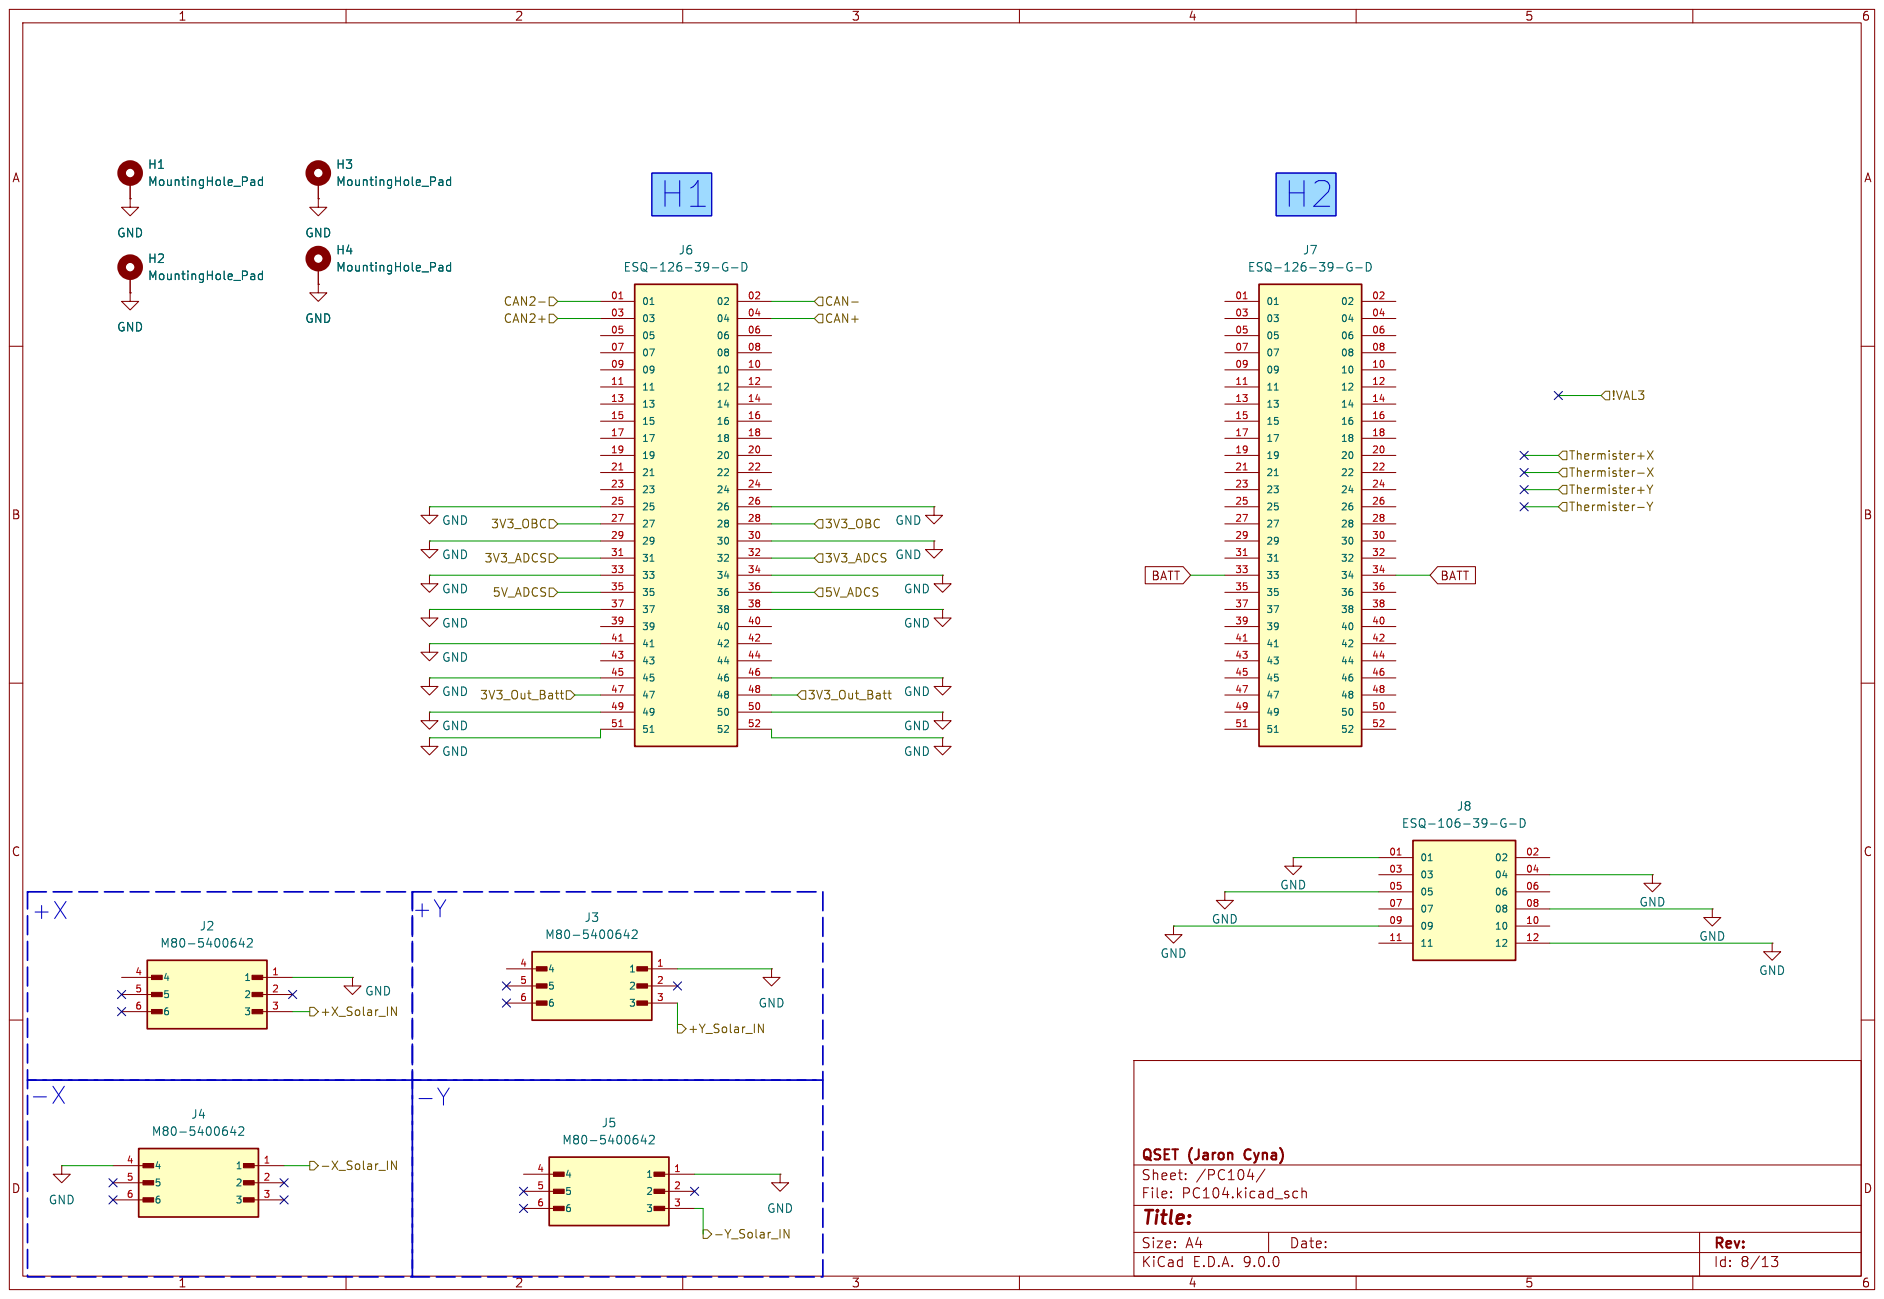
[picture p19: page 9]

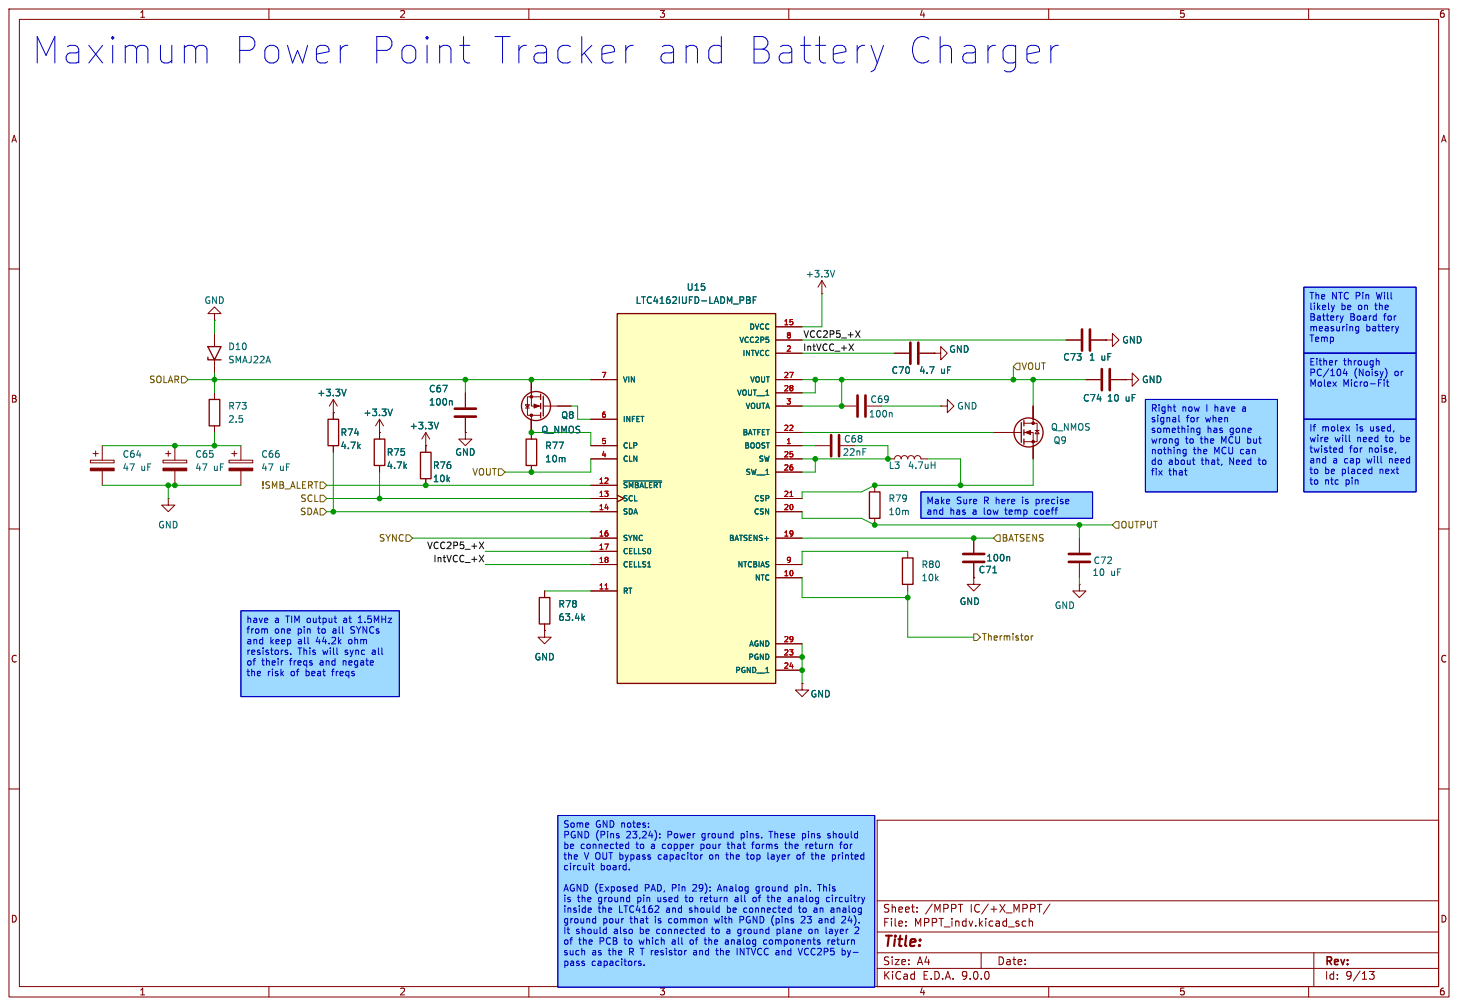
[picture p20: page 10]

Maximum Power Point Tracker and Battery Charger

to ntc pin The NTC Pin Will

If molex is used, wire will need to be

twisted for noise, and a cap will need

do about that, Need to

to be placed next

from one pin to all SYNCs and keep all 44.2k ohm

the risk of beat freqs

is the ground pin used to return all of the analog circuitry
ground pour that is common with PGND (pins 23 and 24).

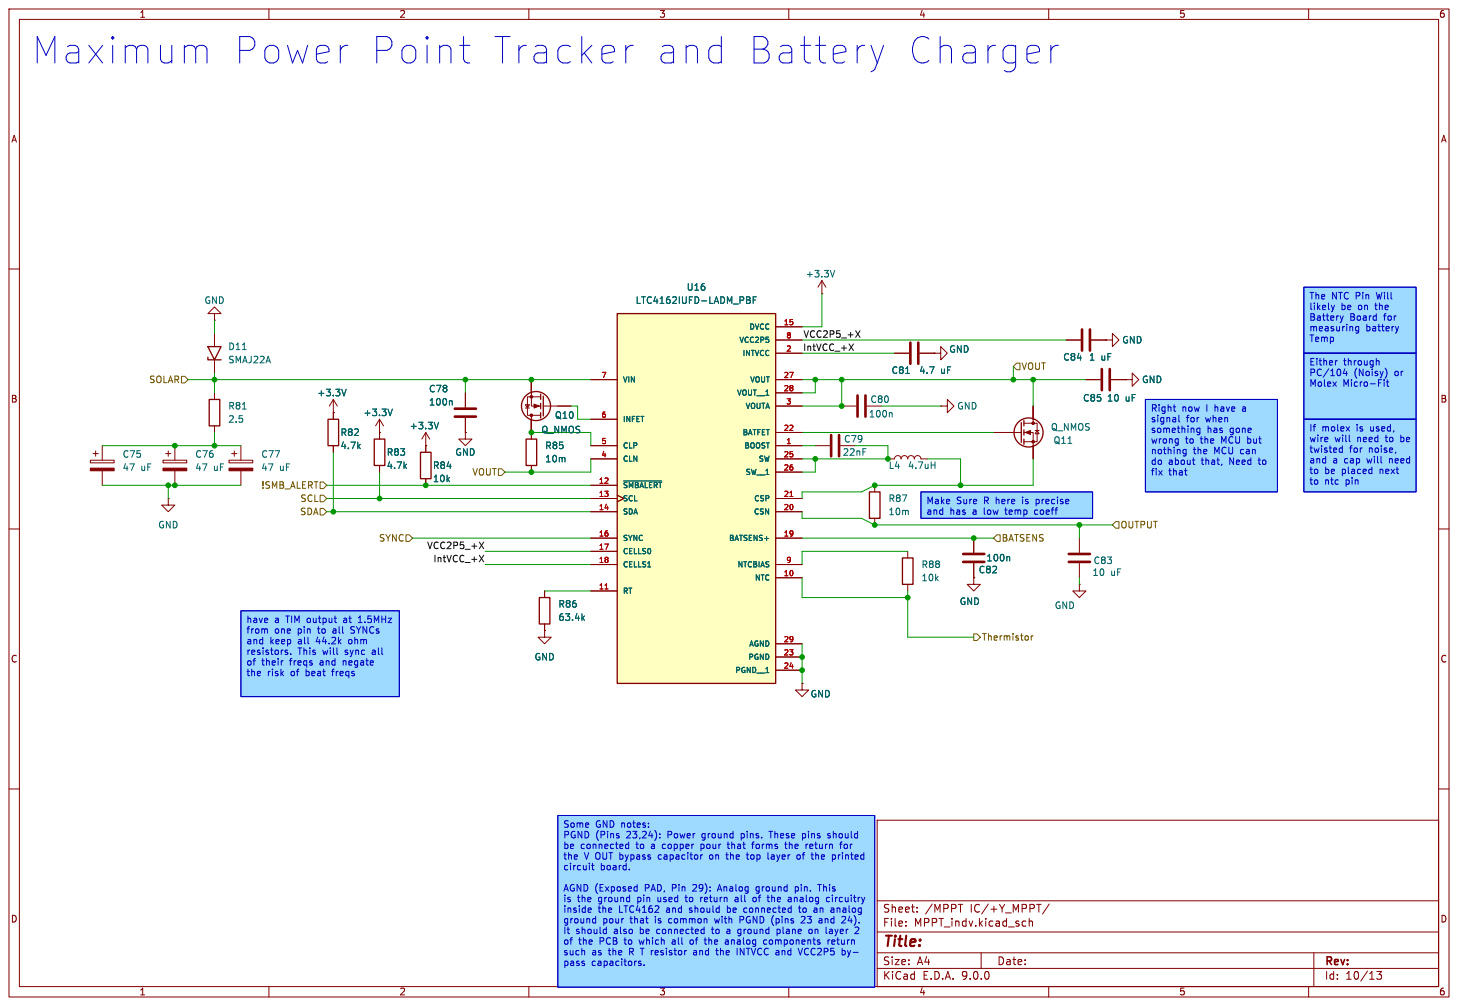
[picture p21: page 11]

Maximum Power Point Tracker and Battery Charger

to ntc pin The NTC Pin Will

If molex is used, wire will need to be

twisted for noise, and a cap will need

do about that, Need to

to be placed next

from one pin to all SYNCs and keep all 44.2k ohm

the risk of beat freqs

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

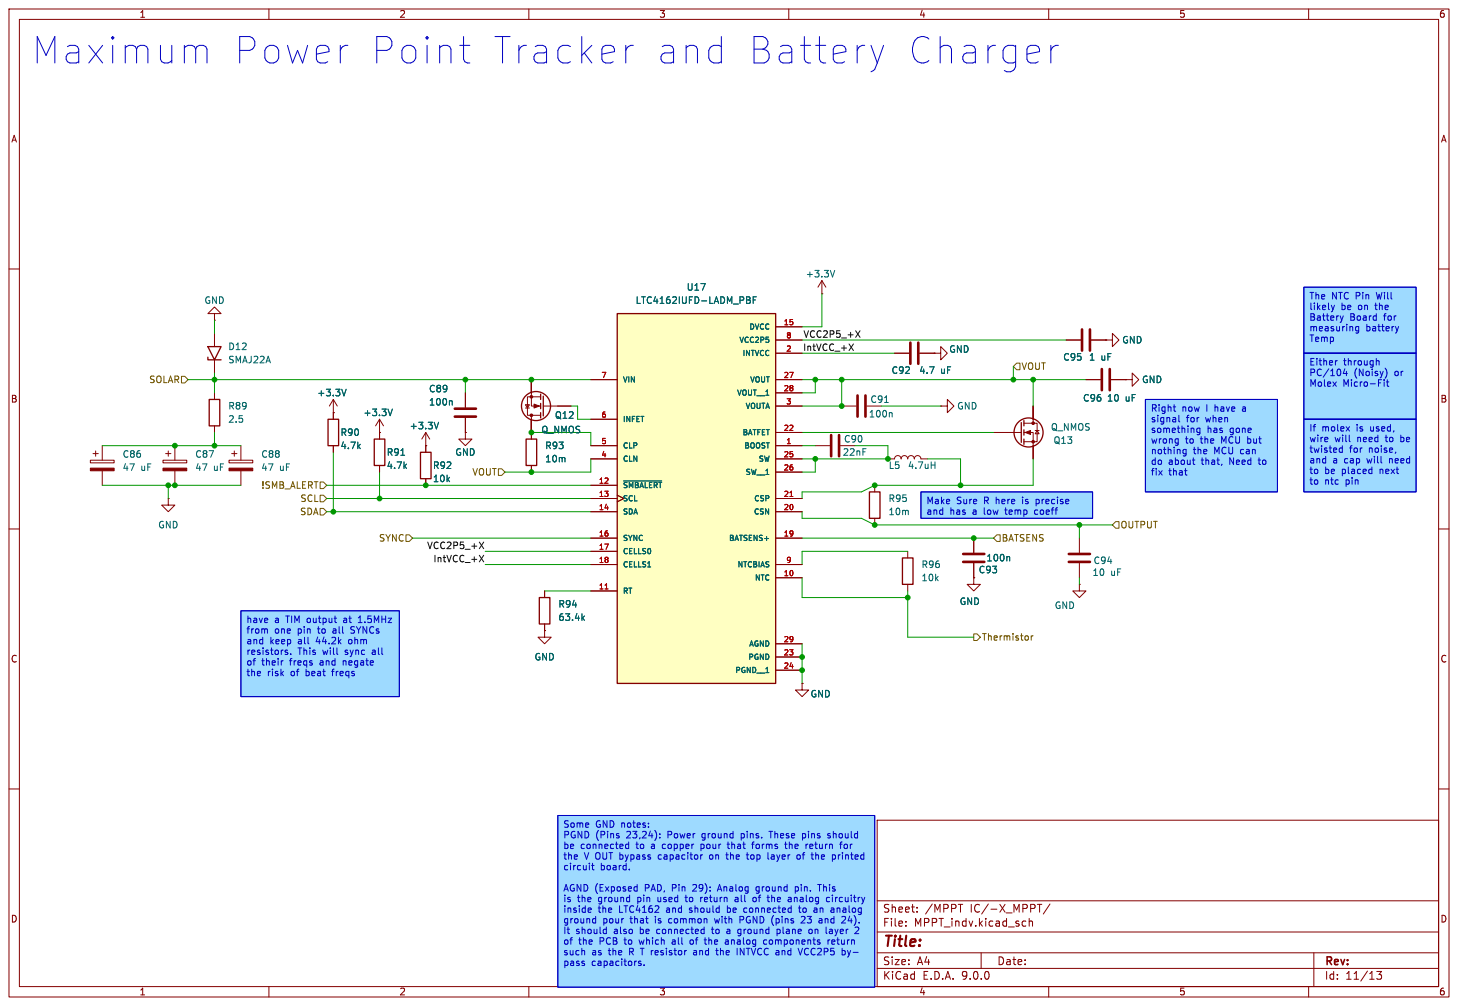
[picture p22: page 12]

Maximum Power Point Tracker and Battery Charger

to ntc pin The NTC Pin Will

If molex is used, wire will need to be

twisted for noise, and a cap will need

do about that, Need to

to be placed next

from one pin to all SYNCs and keep all 44.2k ohm

the risk of beat freqs

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


Maximum Power Point Tracker and Battery Charger

to ntc pin The NTC Pin Will

If molex is used, wire will need to be

twisted for noise, and a cap will need

do about that, Need to

to be placed next

from one pin to all SYNCs and keep all 44.2k ohm

the risk of beat freqs

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

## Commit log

2026-03-14 Pushing all the files
    [12V.kicad_sch, 3.3V.kicad_sch, 5V.kicad_sch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]
2026-03-14 Added 3.3V and 12V lines
    [3.3V.kicad_sch, EPS_mppt_board.kicad_sch, MPPT_IC.kicad_sch]
2026-04-24 Added cap to output of lines
    based on LTSpice Simulation
    [12V.kicad_sch, EPS_mppt_board.kicad_sch, External Watchdog IC.kicad_sch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]
2026-04-24 Added footprints to caps
    [3.3V.kicad_sch, EPS_mppt_board.kicad_sch, External Watchdog IC.kicad_sch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]
2026-04-29 edited 3V3 Logic to add Efuse and UVLO
    [3.3V.kicad_sch, External Watchdog IC.kicad_sch, I2C.kicad_sch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]
2026-04-29 added current sensing and e-fuses
    [EPS_mppt_board.kicad_sch, External Watchdog IC.kicad_sch, MPPT_3.3V_logic.kicad_sch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]
2026-06-09 Added connectors to schematic
    [3.3V.kicad_sch, EPS_mppt_board.csv, EPS_mppt_board.kicad_sch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]
2026-06-18 A bunch of misc schematic changes
    [3.3V.kicad_sch, EPS_mppt_board.kicad_pcb, EPS_mppt_board.kicad_sch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]
2026-06-18 Small schematic changes
    [3.3V.kicad_sch, EPS_mppt_board.kicad_pcb, EPS_mppt_board.kicad_sch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]
2026-06-20 Changed LTC 4412 to 4417, still kinks to work out
    [3.3V.kicad_sch, EPS_mppt_board.kicad_pcb, EPS_mppt_board.kicad_sch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]
2026-06-20 small changes
    [MPPT_3.3V_logic.kicad_sch, MPPT_IC.kicad_sch, MPPT_indv.kicad_sch]
2026-06-24 Started PCB layout
    [3.3V.kicad_sch, 4253.kicad_sch, EPS_mppt_board.kicad_pcb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]
2026-07-04 LTC4162 layout almost done
    [3.3V.kicad_sch, C1210C106M5R2C7186.step, CAP_C2220C_2S_KEM.step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]
2026-07-07 Started layout of the Ideal diode input (LTC4417)
    I'm considering getting rid of the second 3V3 buck but will need to weigh the pros and cons a little more before commiting
    [EPS_mppt_board.kicad_sch, MPPT_3.3V_logic.kicad_sch, MPPT_IC.kicad_sch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]
2026-08-03 Efuses for this board and Battery board
    [3.3V.kicad_sch, EPS_mppt_board.kicad_pcb, EPS_mppt_board.kicad_sch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]
2026-08-13 Mostly done routing, still yet to start DRC
    [EPS_mppt_board.kicad_pcb, EPS_mppt_board.kicad_sch, I2C.kicad_sch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]
2026-08-17 Most DRC errors fixed
    [EPS_mppt_board.kicad_pcb, MPPT_3.3V_logic.kicad_sch]
2026-08-24 Added Batt 1 and Batt 2 charging
    [EPS_mppt_board.kicad_pcb, EPS_mppt_board.kicad_sch, External Watchdog IC.kicad_sch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]
2026-08-30 README and reorganized
    [12V.kicad_sch, 4253.kicad_sch, 5V.kicad_sch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]

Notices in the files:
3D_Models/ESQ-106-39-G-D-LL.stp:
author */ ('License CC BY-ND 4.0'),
